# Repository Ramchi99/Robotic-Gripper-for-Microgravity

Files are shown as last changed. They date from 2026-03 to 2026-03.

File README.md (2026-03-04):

# Development of a Robotic Gripper for Microgravity Applications

<p align="center">
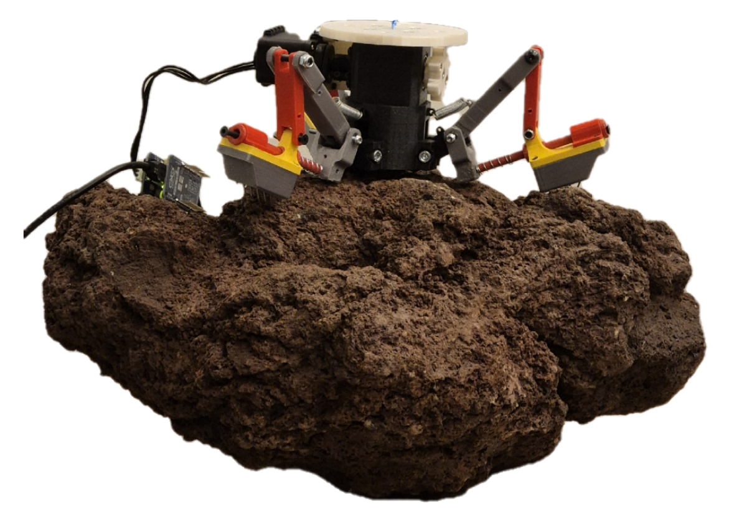
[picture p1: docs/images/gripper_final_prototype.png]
Physical Prototype of the Spacehopper Gripper
  
</p>

This repository contains the hardware designs, firmware, control software, and data evaluation for a functioning prototype of an underactuated robotic gripper designed for applications in microgravity. 

The gripper was developed as part of a Bachelor's Thesis, and is intended to be integrated into **Spacehopper**, an autonomous robot designed to jump in microgravity and reorient in the air to land safely. 

## Testing the Gripper

Here is a video of the final gripper mechanism in action:

<p align="center">
  Gripper in Action
</p>

*(If you prefer higher quality, **[click here to download or view the original .mp4 video](docs/images/gripper_stable.mp4)**)*

## Design Objectives

The mechanical design of this gripping mechanism aimed to fulfill the following primary objectives for reliable use on varied terrain in space:
1. **Reliable Static Gripping:** Ensure safe attachment to various relevant rocky surfaces.
2. **Microgravity Compatibility:** The mechanism must not rely on normal forces (gravity) to maintain its grip.
3. **Underactuated Design:** To reduce weight and complexity, the gripper is underactuated, using a single motor to drive all three legs via a differential mechanism, combined with a spring-loaded passive release mechanism.
4. **Space-Grade Design Principles:** While the current prototype is primarily 3D printed, the architecture is designed such that it can be manufactured using space-gradable materials in the future. This means avoiding components prone to dust jamming (like exposed gears) and avoiding compliant materials (like soft polymers) that would rapidly degrade in the space environment.

## Repository Structure

This repository is structured for modularity and easy reproduction. You'll find everything you need to build the physical gripper, program its microcontroller, and evaluate its physical performance using the custom ROS control interface.

```text
Robotic-Gripper-for-Microgravity/
├── hardware/                 # Everything needed to physically build the gripper
│   ├── Gripper_V06.stl       # Full 3D Assembly Model (Interactive in browser)
│   ├── cad/                  # Source CAD files (e.g., .prt, .stp, .3mf) 
│   │   └── design_iterations/# Historical CAD files for previous gripper versions (V01-V05)
│   └── stl/                  # Ready-to-print 3D models for the individual parts
│
├── firmware/                 # Code that runs directly on the microcontrollers
│   └── ax12a_controller/     # Arduino code (.ino) for Dynamixel AX-12A motors
│
├── software/                 # High-level software, ROS nodes, and testing scripts
│   └── franka_ft_reader/     # ROS package containing the controller nodes and measurement logger
│
├── data_evaluation/          # Data collected during physical testing on different rock types
│   ├── notebooks/            # Jupyter notebooks containing the evaluation scripts and plots
│   └── raw_data/             # Raw .csv logs from the Franka arm tests
│
└── docs/                     # Documentation and final reports
    ├── Climbing_robotic_gripper_report.pdf # Final detailed Bachelor Thesis report
    └── Final_Presentation_Slides.pdf       # Summary presentation of the project
```

## Hardware & Manufacturing

**[Click here to view the Interactive 3D Assembly Model of the Gripper](hardware/Gripper_V06.stl)**

> **Important Note regarding CAD vs. Physical Prototype:**
> The `Gripper_V06.prt` file represents the final *modeled* iteration of the design. However, during physical testing, spontaneous and rapid modifications had to be made to the gripper legs to achieve a functional grip. These final manual adjustments are **not** reflected in the CAD files, but can be seen in the photographs within the final thesis report. 

The physical prototype is composed of custom 3D printed parts and off-the-shelf Dynamixel Actuators. 
* To print your own parts, head over to `hardware/stl`. 
* To modify the design, refer to the CAD source files inside `hardware/cad`. 
* Detailed assembly instructions, kinematic diagrams, and mechanical analysis can be found inside the final report located in `docs/`.

## Software & Testing

The `software` directory contains the `franka_ft_reader` ROS package. This package was used to drive a Franka Emika Panda robotic arm to perform repeatable, precise force interactions with the gripper against various asteroid-analog rock samples (Asphalt, Limestone, Volcanic Lava Rock, Breccia, Slate, and Sediment). 

### Dependencies
* ROS Noetic (or compatible)
* [franka_ros](https://frankaemika.github.io/docs/franka_ros.html)

## Data & Evaluation

Detailed evaluations of the grip strength, spine angles (40 to 90 degrees), and dynamic shock responses are provided in the `data_evaluation` directory. 
* **Raw test data:** Available as `.csv` logs under `data_evaluation/raw_data`.
* **Plots and analysis:** Jupyter Notebooks demonstrating exactly how the data was cleaned and analyzed are located in `data_evaluation/notebooks`.

---
## License and Copyright

This project is licensed under the MIT License. This means you are free to use, copy, modify, merge, publish, distribute, sublicense, and/or sell copies of the software and hardware designs, provided that the original copyright notice and permission notice are included in all copies or substantial portions of the work.

*Copyright (c) 2024 Fiona Martin and Simon Ramchandani. Created as part of a Bachelor's Thesis project affiliated with the ETH Robotic Systems Lab.*

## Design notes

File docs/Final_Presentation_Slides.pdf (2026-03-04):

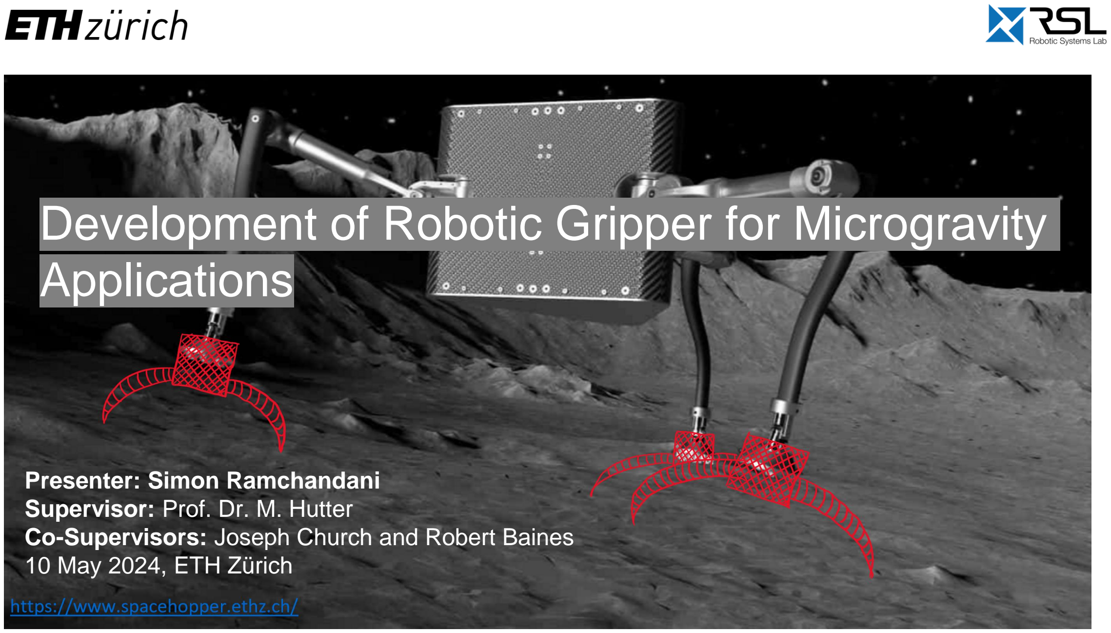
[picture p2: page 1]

# Development of Robotic Gripper for Microgravity Applications

Presenter: Simon Ramchandani
Supervisor: Prof. Dr. M. Hutter
Co-Supervisors: Joseph Church and Robert Baines 10 May 2024, ETH Zürich

## Motivation for the whole projects

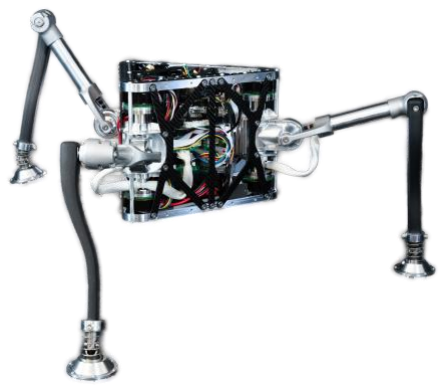
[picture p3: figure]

- Exploring surface of asteroids and other microgravitational environments
- Design a robotic gripper for robots like Spacehopper

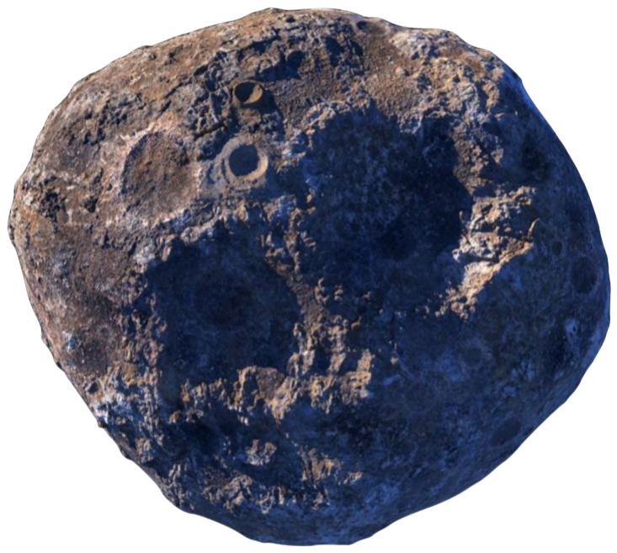
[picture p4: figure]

- Considerations:
- grasp and hold on to rocks
- should work in zero gravity
- designed for space
06.05.2020 | 2

## Overview and division of workload

Fiona
- Design of gripping mechanism

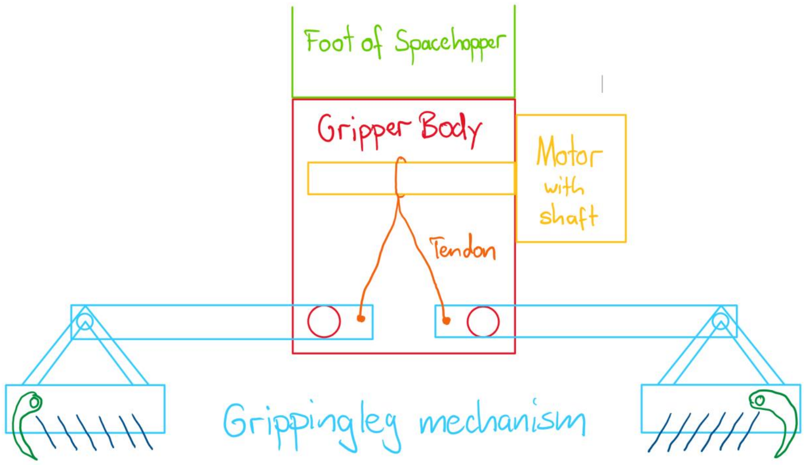
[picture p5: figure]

Simon
- Design of gripper body
- Actuation of gripper
- Setup and conducting tests:

-selecting rock to gripp

- determining the capable adhesion force in tangential and normal direction
- test different hooking mechanisms

## Gripper body Design

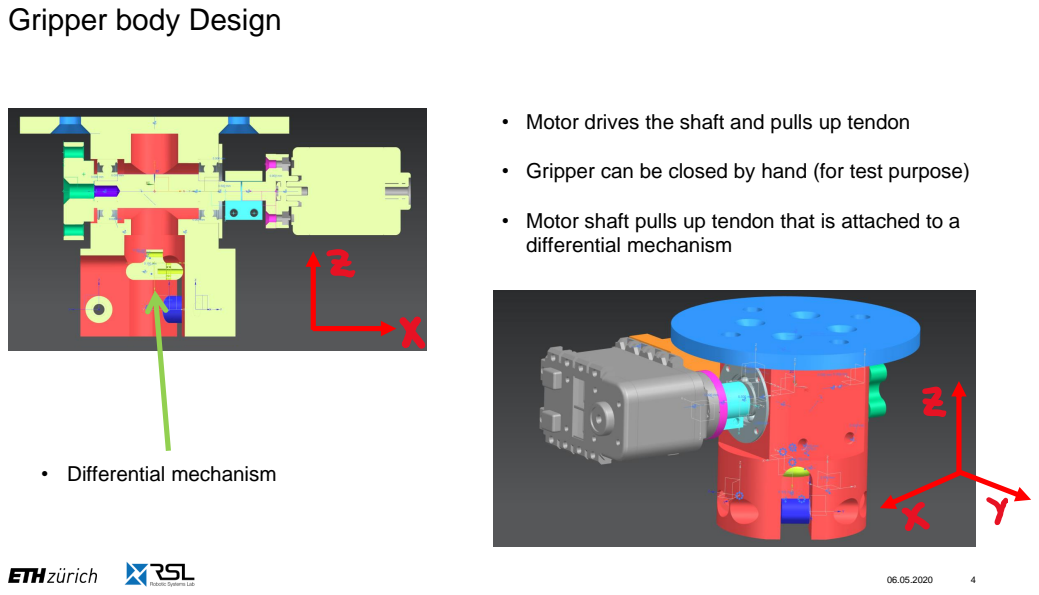
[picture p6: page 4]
• Differential mechanism

• Motor drives the shaft and pulls up tendon

• Gripper can be closed by hand (for test purpose)

• Motor shaft pulls up tendon that is attached to a
differential mechanism

## Gripper body Design – Differential mechanism

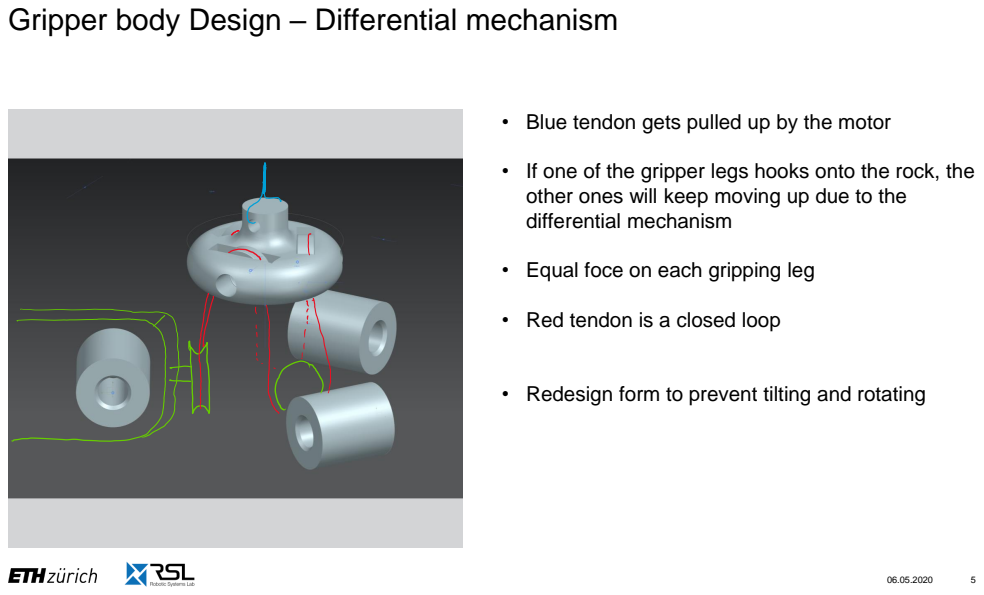
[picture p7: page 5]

• Blue tendon gets pulled up by the motor

• If one of the gripper legs hooks onto the rock, the
other ones will keep moving up due to the
differential mechanism

• Equal foce on each gripping leg

• Red tendon is a closed loop

• Redesign form to prevent tilting and rotating

## Testing – Two main hooking mechanism

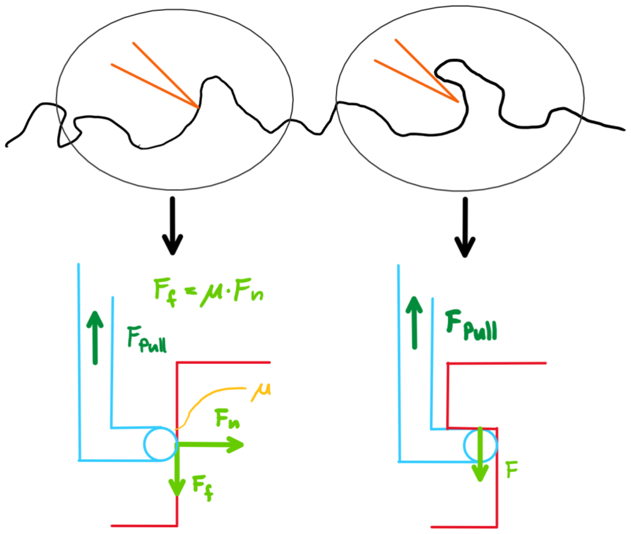
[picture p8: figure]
First Mechanism - Friction

- 1. Mechanism based on friction (left)

The bigger the generated force in tangential direction, the bigger the the capable pulling force

- 2. Mechanism based on geometry (right)

For this the geometry and angle of the spine is the main contributing factor

(a force in tangential direction is necessary to keep the spine in his place)

## Test setup in the literature

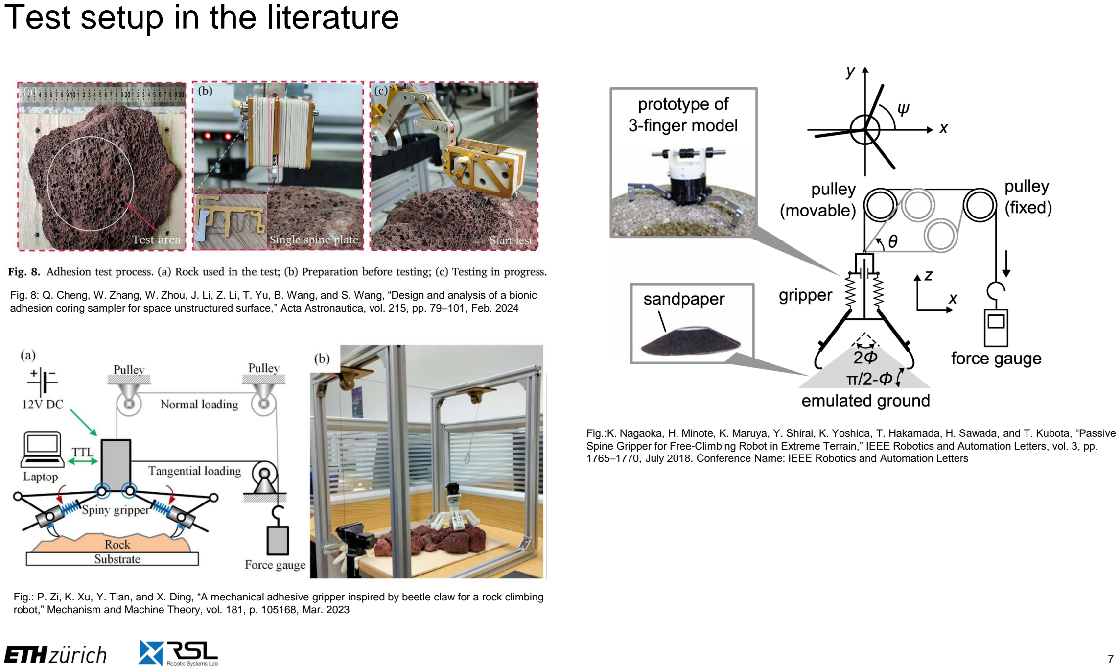
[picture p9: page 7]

7

Fig. 8: Q. Cheng, W. Zhang, W. Zhou, J. Li, Z. Li, T. Yu, B. Wang, and S. Wang, “Design and analysis of a bionic adhesion coring sampler for space unstructured surface,” Acta Astronautica, vol. 215, pp. 79–101, Feb. 2024

Fig.: P. Zi, K. Xu, Y. Tian, and X. Ding, “A mechanical adhesive gripper inspired by beetle claw for a rock climbing robot,” Mechanism and Machine Theory, vol. 181, p. 105168, Mar. 2023

Fig.:K. Nagaoka, H. Minote, K. Maruya, Y. Shirai, K. Yoshida, T. Hakamada, H. Sawada, and T. Kubota, “Passive Spine Gripper for Free-Climbing Robot in Extreme Terrain,” IEEE Robotics and Automation Letters, vol. 3, pp. 1765–1770, July 2018. Conference Name: IEEE Robotics and Automation Letters

## Test setup

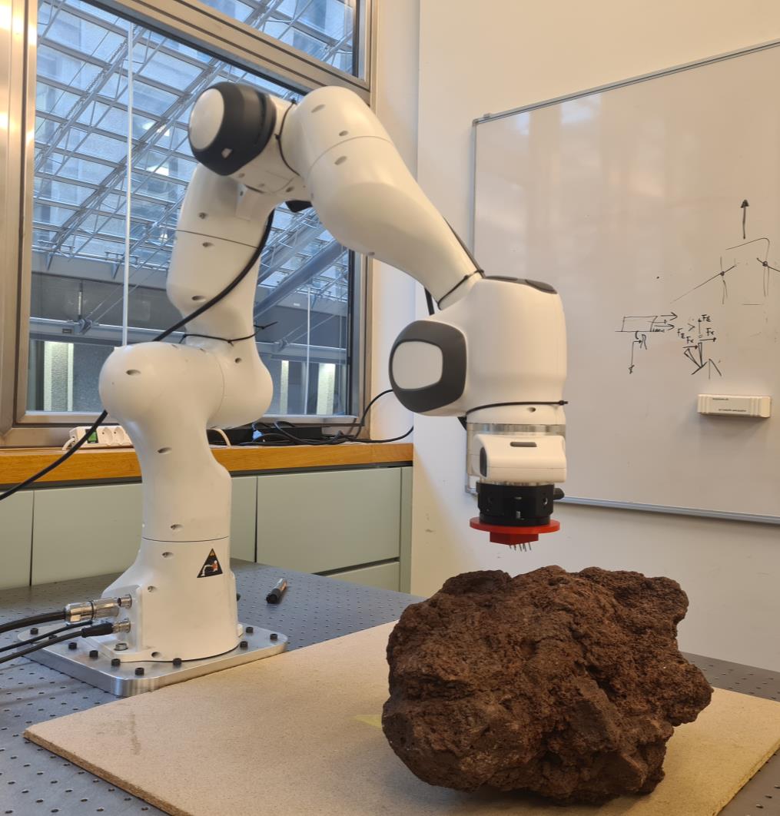
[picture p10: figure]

- Gripper or subpart of gripper attached to Franka arm with force-torque-sensor

versatile in the movement of the arm

measure forces and torques in all directions

- Decided to test on porous volcanic rock

exists widely on mars and other numerous planets

unregular surface to capture as many surface structures as possible

8

## Testing tangential force (y-force)

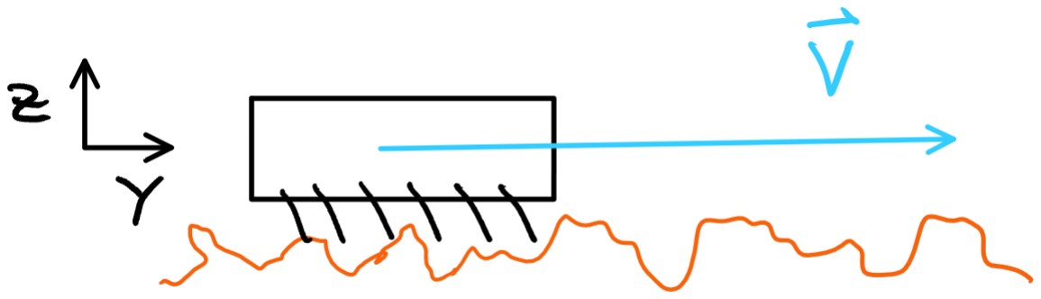
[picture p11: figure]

- Track velocity in y-direction with Franka-Arm
- Measure the forces in x, y and z direction
- Primarily interested in the capable y-force bevor detaching

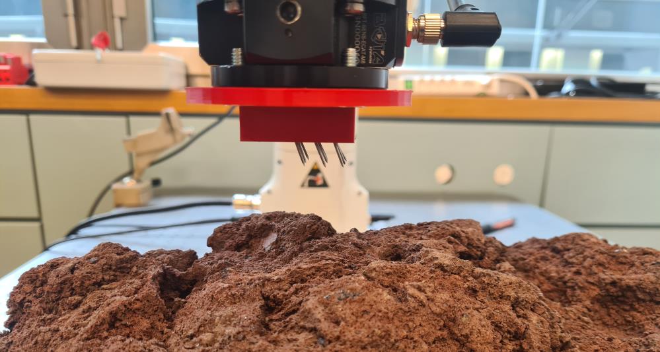
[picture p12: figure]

- Test different spine angles

## Testing tangential force (y-force)

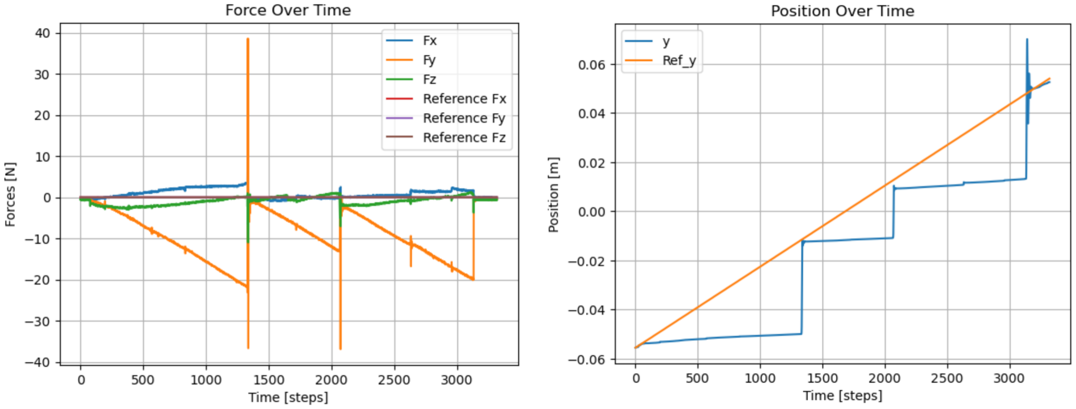
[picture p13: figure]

- Approximately 10 to 20 Newtons before detaching

10

## Future Testing – pulling force and hook implementation

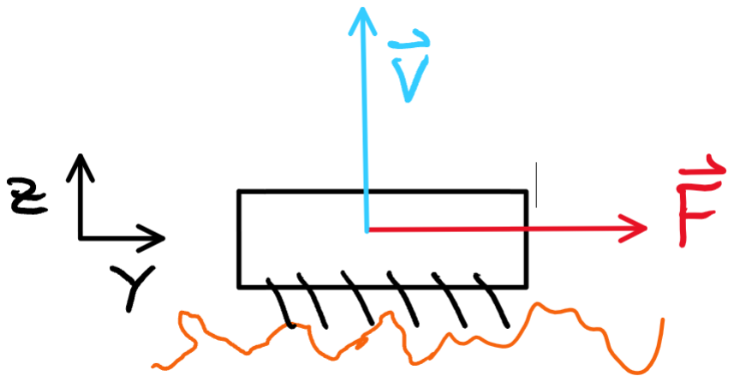
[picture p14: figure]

- Apply force in y direction and velocity in z direction
- Measure the z force (pulling force)

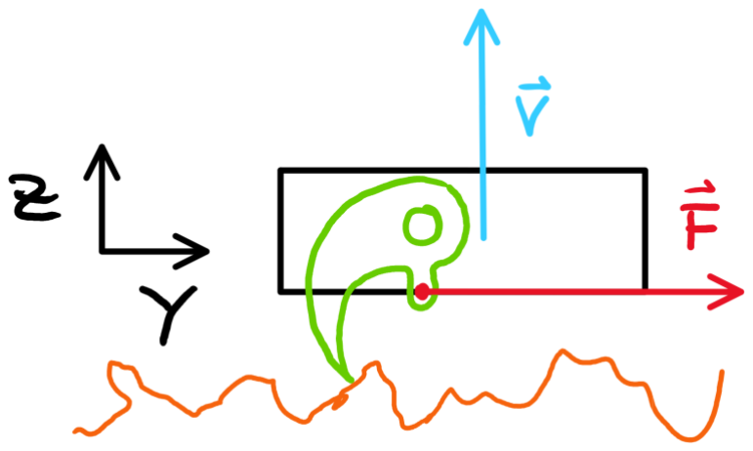
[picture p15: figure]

- Test hook mechanism with different configurations
- Also measure the z force

12

Simon Ramchandani
Student
simonra@student.ethz.ch

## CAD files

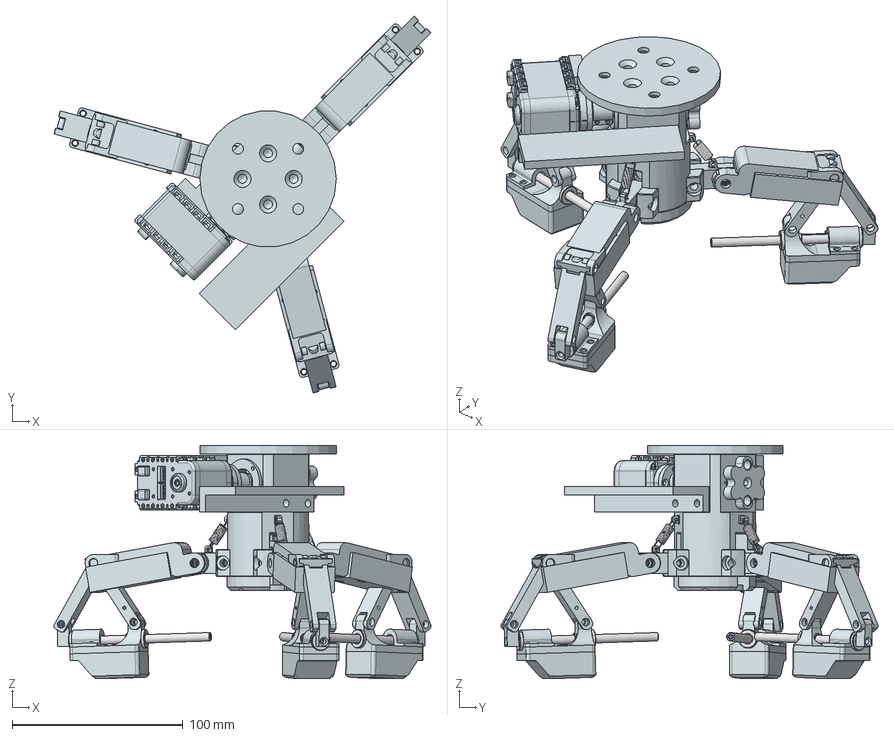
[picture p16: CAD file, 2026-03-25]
hardware/step/Gripper_V06.stp
221.0 x 221.0 x 136.8 mm
motor_adapter_06_3D
Adapter_V02
tendon_differential
pulley_differential x 12
ballbearing_fix
motor_axel_02
tendon_differential_02
PRT0001
PRT0002
PRT0003 x 4
PRT0004 x 2
PRT0005
PRT0006
PRT0007
skf_bearing_626_2_x_t x 2
dynamixel_adapter
dynamixel_axle_02
fixing_device_3D
kupplung_02
Rock_01
dowel_pin x 3
skf_bearing_w_618_1_5_2_x_t x 3
tendon_differential_04
arduino_holder
testleg_05 x 3
gripperleg x 3
Block_90_degree x 3
Sodemann 40900_step x 3
floor_for_body
nds_000001_001_M_link_body1 x 3
001_000001_001_M_Link1_f1 x 3
001_000001_001_M_Link2_f1 - Copy x 3
001_000001_001_M_insert x 3
nds_000001_001_M_top_x1block x 3
nds_000001_001_M_Holder_links x 3
bushing inner d_5_ L_12 x 6
nds_000002_031_M_Block_50 x 3
SSFJW5-85-M3-N3 x 3

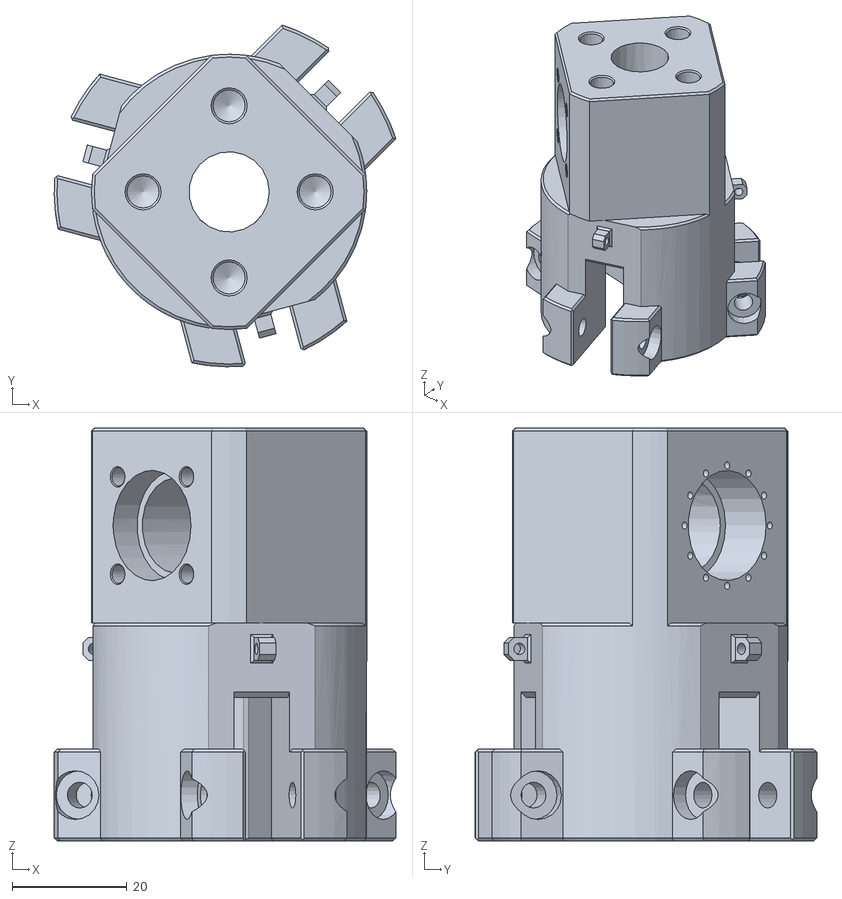
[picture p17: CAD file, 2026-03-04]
hardware/stl/motor_adapter_06_3D.stl
59.6 x 59.6 x 72.0

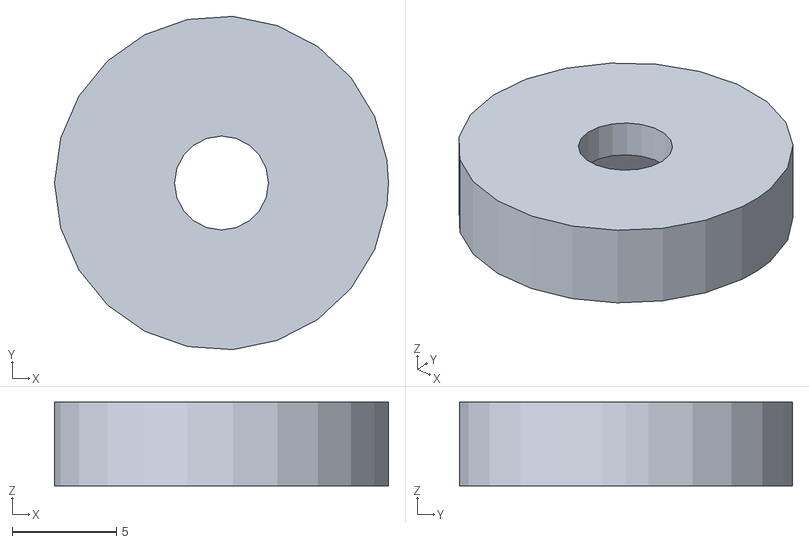
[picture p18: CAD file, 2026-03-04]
hardware/stl/fixing_disk.stl
16.0 x 16.0 x 4.00

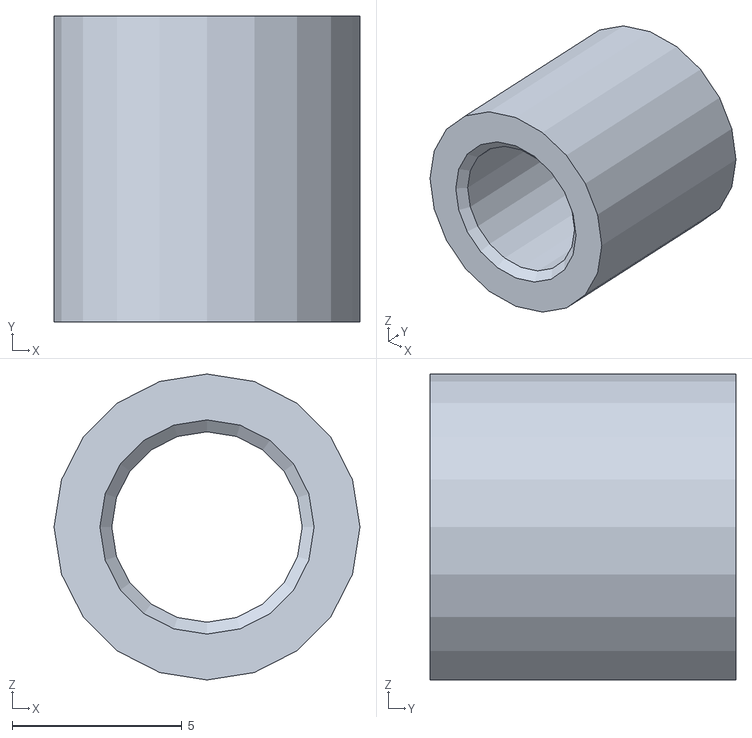
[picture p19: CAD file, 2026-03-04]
hardware/stl/dowel_pin_3D.stl
9.00 x 9.00 x 9.00

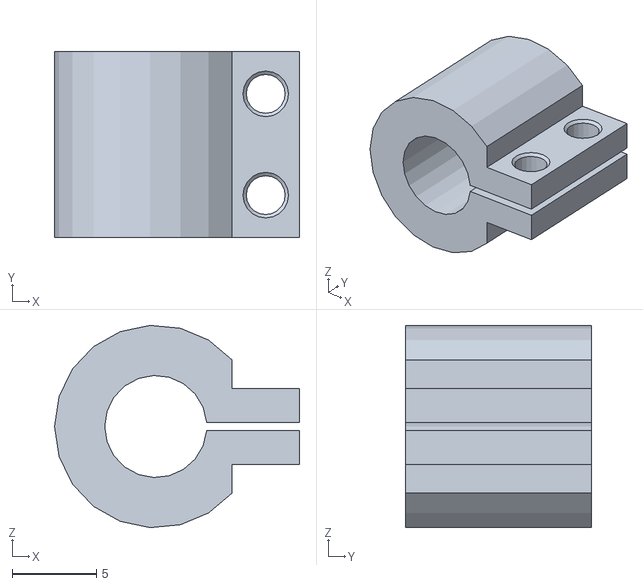
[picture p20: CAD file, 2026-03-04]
hardware/stl/kupplung_3D.stl
14.5 x 11.0 x 12.0

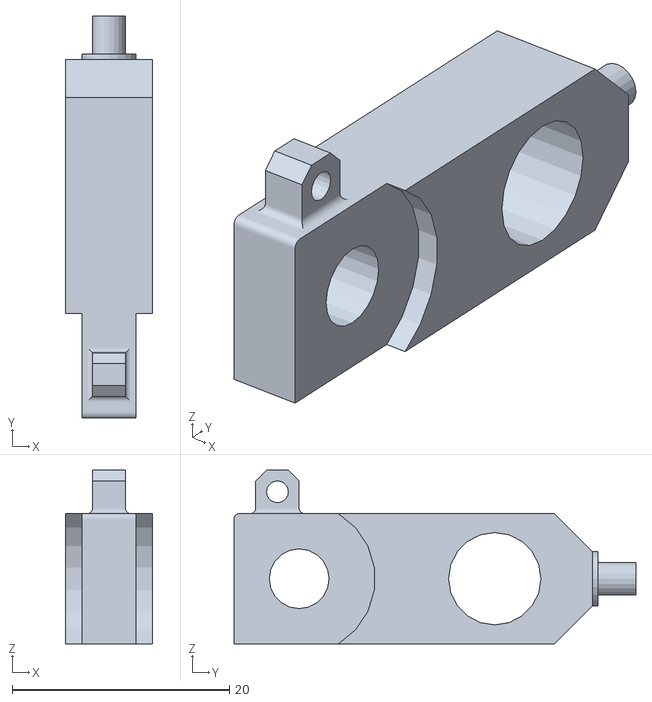
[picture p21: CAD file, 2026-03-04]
hardware/stl/testleg_04.stl
8.00 x 37.0 x 16.0

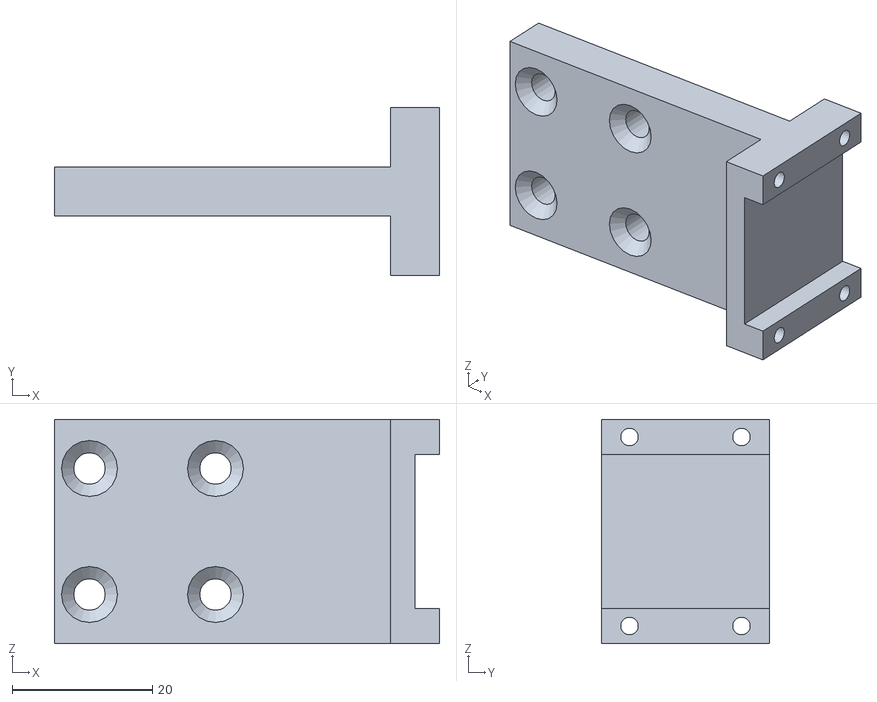
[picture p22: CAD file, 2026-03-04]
hardware/stl/dynamixel_adapter.stl
55.0 x 24.0 x 32.0

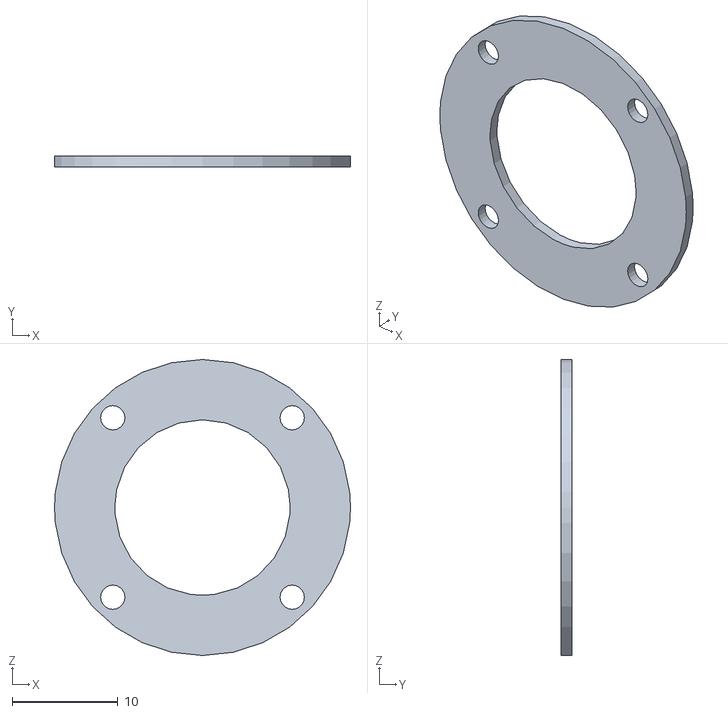
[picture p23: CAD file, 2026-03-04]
hardware/stl/ballbearing_fix.stl
28.0 x 1.00 x 28.0

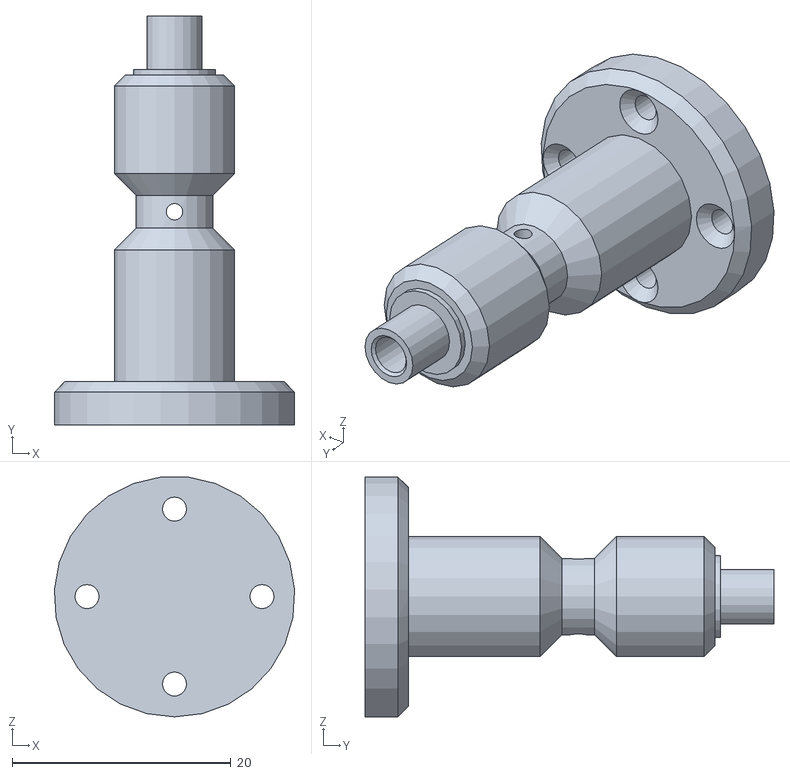
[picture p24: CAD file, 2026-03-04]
hardware/stl/motor_shaft_3D_printing.stl
22.0 x 37.4 x 21.9

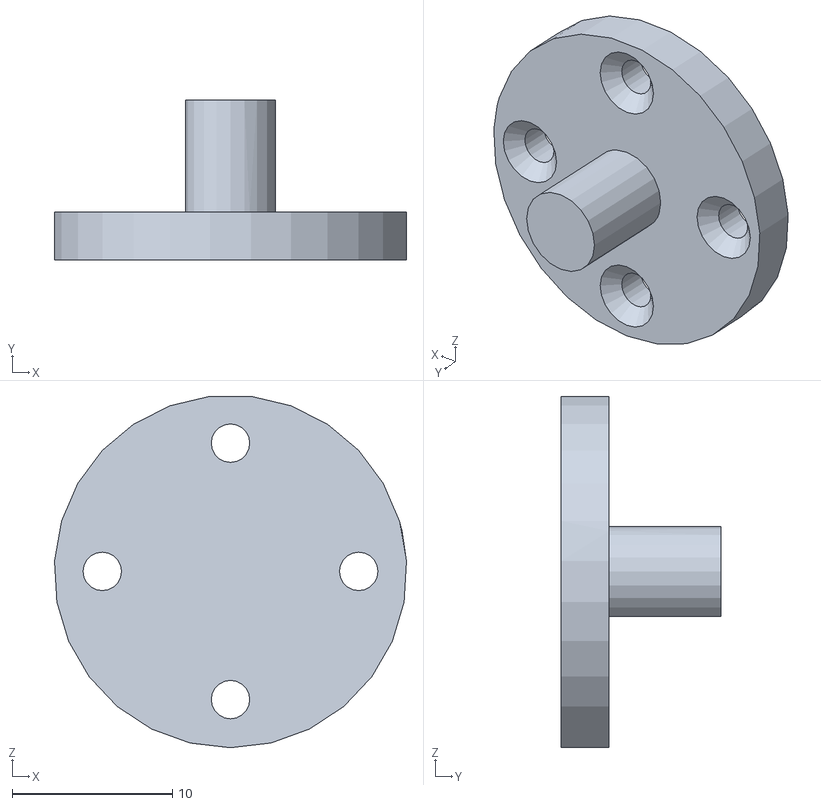
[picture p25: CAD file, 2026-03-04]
hardware/stl/dynamixel_axle.stl
22.0 x 10.0 x 21.9

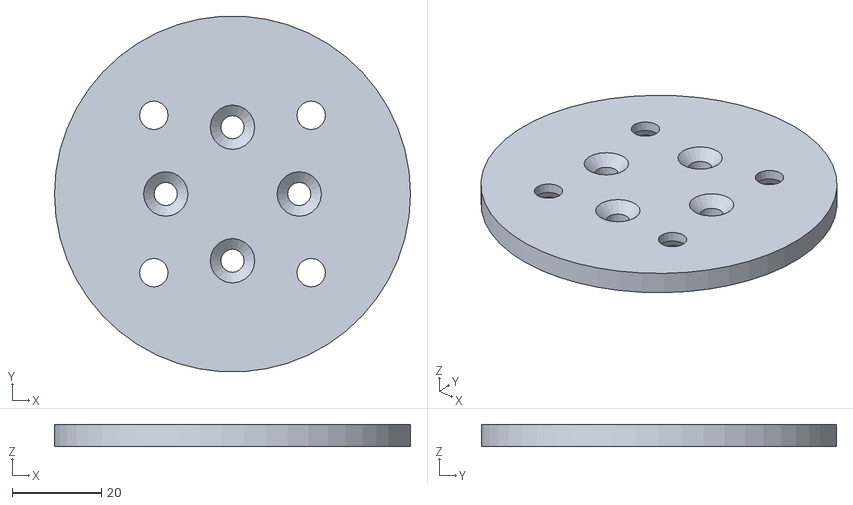
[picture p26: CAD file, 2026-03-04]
hardware/stl/Adapter_V02_3D.stl
80.0 x 79.8 x 5.00

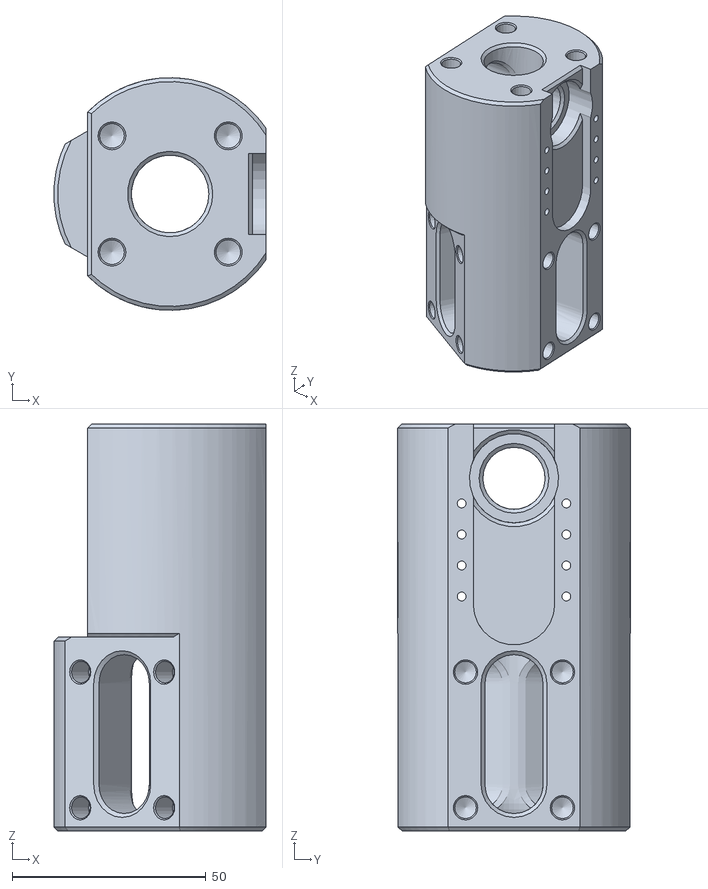
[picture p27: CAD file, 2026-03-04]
hardware/stl/motor_adapter_03_3D_printing.stl
54.7 x 60.0 x 105.0

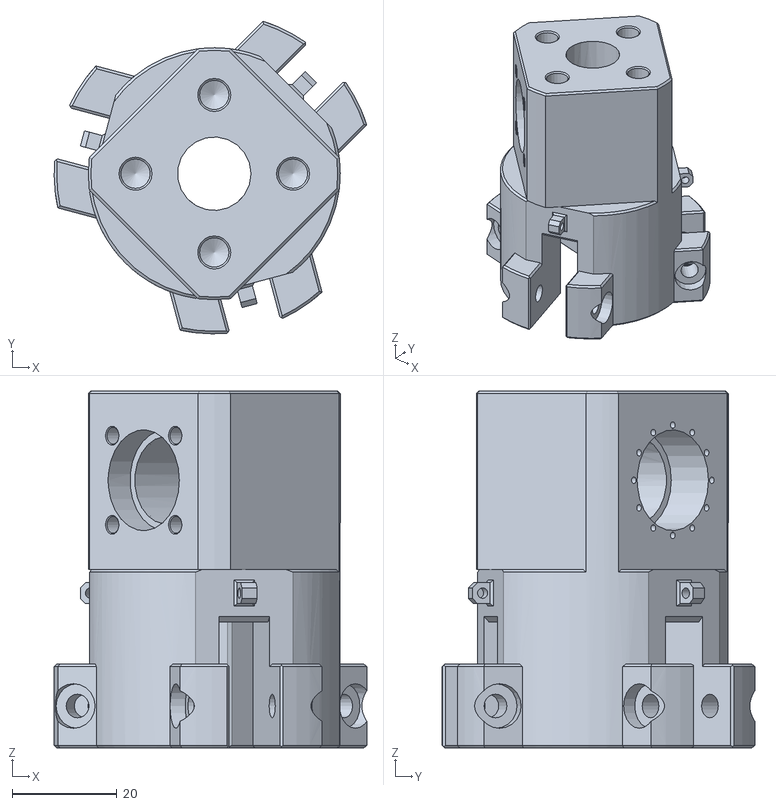
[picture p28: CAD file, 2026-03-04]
hardware/stl/motor_adapter_05_3D_longer.stl
59.6 x 59.6 x 68.0

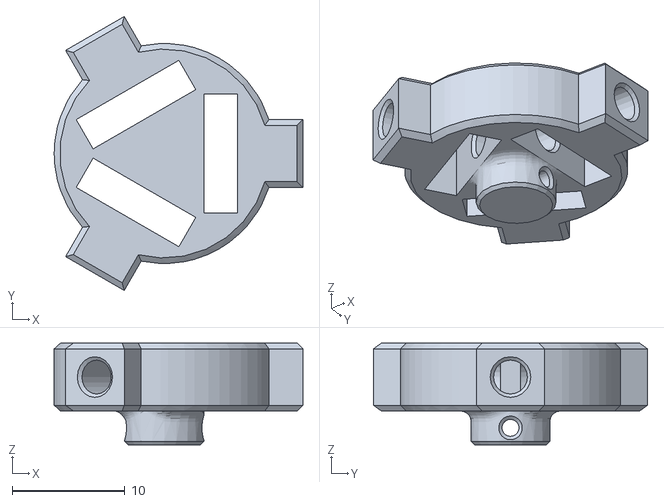
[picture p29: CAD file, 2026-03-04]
hardware/stl/tendon_differential_04.stl
22.0 x 24.3 x 9.00

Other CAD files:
hardware/stl/motor_adapter_05_3D.stl
hardware/stl/linkage_pin_3D_printing.stl
hardware/stl/tendon_differential_04_2.stl
hardware/stl/tendon_linkage_part_03_3D_printing.stl
hardware/cad/001_000001_001_M_Link1_f1.prt
hardware/cad/001_000001_001_M_Link2_f1 - Copy.prt
hardware/cad/001_000001_001_M_insert.prt
hardware/cad/ASM0002_ASM.prt
hardware/cad/AX-12A_stp.prt
hardware/cad/Adapter_V02.prt
hardware/cad/Block_90_degree.prt
hardware/cad/Gripper_V06.prt
hardware/cad/PRT0001.prt
hardware/cad/PRT0002.prt
hardware/cad/PRT0003.prt
hardware/cad/PRT0004.prt
hardware/cad/PRT0005.prt
hardware/cad/PRT0006.prt
hardware/cad/PRT0007.prt
hardware/cad/SSFJW5-85-M3-N3.prt
hardware/cad/Sodemann 40900_step.prt
hardware/cad/arduino_holder.prt
hardware/cad/ballbearing_fix.prt
hardware/cad/bushing inner d_5_ L_12.prt
hardware/cad/design_iterations/001_000001_00_M_Link1_body.prt
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

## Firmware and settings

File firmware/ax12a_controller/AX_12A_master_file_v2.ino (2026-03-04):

#include <DynamixelShield.h>

/*
Baud Rate Values for Dynamixel Motors:

Value   Baud Rate (bps)    Margin of Error
1       1M                  0.000%
3       500,000             0.000%
4       400,000             0.000%
7       250,000             0.000%
9       200,000             0.000%
16      115200              -2.124%
34      57600               0.794%
103     19200               -0.160%
207     9600                -0.160%
*/

#if defined(ARDUINO_AVR_UNO) || defined(ARDUINO_AVR_MEGA2560)
  #include <SoftwareSerial.h>
  SoftwareSerial soft_serial(7, 8); // DYNAMIXELShield UART RX/TX
  #define DEBUG_SERIAL soft_serial
#elif defined(ARDUINO_SAM_DUE) || defined(ARDUINO_SAM_ZERO)
  #define DEBUG_SERIAL SerialUSB    
#else
  #define DEBUG_SERIAL Serial
#endif

//This example is written for DYNAMIXEL AX-12A with Protocol 1.0.

#define OPERATING_MODE_ADDR_LEN     2

/*The Control Table is divided into 2 Areas. 
Data in the RAM Area is reset to initial values 
when the power is reset(Volatile). On the other 
hand, data in the EEPROM Area is maintained even 
when the device is powered off(Non-Volatile).*/

//Control Table of EEPROM Area
#define MODEL_NUMBER_ADDR           0
#define MODEL_NUMBER_ADDR_LEN       2
#define FIRMWARE_VERSION_ADDR       2
#define FIRMWARE_VERSION_ADDR_LEN   1
#define ID_ADDR                     3
#define ID_ADDR_LEN                 1
#define BAUDRATE_ADDR               4
#define BAUDRATE_ADDR_LEN           1
#define RETURN_DELAY_TIME_ADDR      5
#define RETURN_DELAY_TIME_ADDR_LEN  1
#define CW_ANGLE_LIMIT_ADDR         6
#define CW_ANGLE_LIMIT_ADDR_LEN     2
#define CCW_ANGLE_LIMIT_ADDR        8
#define CCW_ANGLE_LIMIT_ADDR_LEN    2
#define TEMPERATURE_LIMIT_ADDR      11
#define TEMPERATURE_LIMIT_ADDR_LEN  1
#define MIN_VOLTAGE_LIMIT_ADDR      12
#define MIN_VOLTAGE_LIMIT_ADDR_LEN  1
#define MAX_VOLTAGE_LIMIT_ADDR      13
#define MAX_VOLTAGE_LIMIT_ADDR_LEN  1
#define MAX_TORQUE_ADDR             14
#define MAX_TORQUE_ADDR_LEN         2
#define STATUS_RETURN_LEVEL_ADDR    16
#define STATUS_RETURN_LEVEL_ADDR_LEN 1
#define ALARM_LED_ADDR              17
#define ALARM_LED_ADDR_LEN          1
#define SHUTDOWN_ADDR               18
#define SHUTDOWN_ADDR_LEN           1

//Control Table of RAM Area
#define TORQUE_ENABLE_ADDR           24
#define TORQUE_ENABLE_ADDR_LEN       1
#define LED_ADDR                     25
#define LED_ADDR_LEN                 1
#define CW_COMPLIANCE_MARGIN_ADDR    26
#define CW_COMPLIANCE_MARGIN_ADDR_LEN 1
#define CCW_COMPLIANCE_MARGIN_ADDR   27
#define CCW_COMPLIANCE_MARGIN_ADDR_LEN 1
#define CW_COMPLIANCE_SLOPE_ADDR     28
#define CW_COMPLIANCE_SLOPE_ADDR_LEN 1
#define CCW_COMPLIANCE_SLOPE_ADDR    29
#define CCW_COMPLIANCE_SLOPE_ADDR_LEN 1
#define GOAL_POSITION_ADDR           30
#define GOAL_POSITION_ADDR_LEN       2
#define MOVING_SPEED_ADDR            32
#define MOVING_SPEED_ADDR_LEN        2
#define TORQUE_LIMIT_ADDR            34
#define TORQUE_LIMIT_ADDR_LEN        2
#define PRESENT_POSITION_ADDR        36
#define PRESENT_POSITION_ADDR_LEN    2
#define PRESENT_SPEED_ADDR           38
#define PRESENT_SPEED_ADDR_LEN       2
#define PRESENT_LOAD_ADDR            40
#define PRESENT_LOAD_ADDR_LEN        2
#define PRESENT_VOLTAGE_ADDR         42
#define PRESENT_VOLTAGE_ADDR_LEN     1
#define PRESENT_TEMPERATURE_ADDR     43
#define PRESENT_TEMPERATURE_ADDR_LEN 1
#define REGISTERED_ADDR              44
#define REGISTERED_ADDR_LEN          1
#define MOVING_ADDR                  46
#define MOVING_ADDR_LEN              1
#define LOCK_ADDR                    47
#define LOCK_ADDR_LEN                1
#define PUNCH_ADDR                   48
#define PUNCH_ADDR_LEN               2

#define TIMEOUT 100    //default communication timeout 10ms



const uint8_t DXL_ID = 1;
const float DXL_PROTOCOL_VERSION = 1.0;
const uint32_t baudrate = 1000000;

DynamixelShield dxl;

//use as parameters for some configurations

uint8_t returned_id = 0;
uint8_t returned_baudrate = 0;
uint16_t present_position = 0;
uint16_t present_speed = 0;

uint8_t turn_on = 1;
uint8_t turn_off = 0;

uint16_t goalPosition1 = 300;
uint16_t goalPosition2 = 500;

float Kp = 2; // Proportional gain
uint16_t goal_position = 1022; // Default goal position (middle of the range)


void setup() {
  DEBUG_SERIAL.begin(115200);   // Set debugging port baudrate to 115200bps
  while(!DEBUG_SERIAL);         // Wait until the serial port for terminal is opened

  // Set Port baudrate to 1000000bps. This has to match with DYNAMIXEL baudrate (AX-12A).
  dxl.begin(baudrate);
  
  // Set Port Protocol Version. This has to match with DYNAMIXEL protocol version.
  dxl.setPortProtocolVersion(DXL_PROTOCOL_VERSION);

  DEBUG_SERIAL.print("Read for PROTOCOL ");
  DEBUG_SERIAL.print(DXL_PROTOCOL_VERSION, 1);
  DEBUG_SERIAL.print(", ID ");
  DEBUG_SERIAL.println(DXL_ID);

  // Read DYNAMIXEL ID
  dxl.read(DXL_ID, ID_ADDR, ID_ADDR_LEN, (uint8_t*)&returned_id, sizeof(returned_id), TIMEOUT);
  DEBUG_SERIAL.print("ID : ");
  DEBUG_SERIAL.println(returned_id);
  delay(100);
  
  // Read DYNAMIXEL Baudrate
  dxl.read(DXL_ID, BAUDRATE_ADDR, BAUDRATE_ADDR_LEN, (uint8_t*)&returned_baudrate, sizeof(returned_baudrate), TIMEOUT);
  DEBUG_SERIAL.print("Baud Rate : ");
  DEBUG_SERIAL.println(returned_baudrate);
  delay(100);
  
  // Read DYNAMIXEL Present Position
  dxl.read(DXL_ID, PRESENT_POSITION_ADDR, PRESENT_POSITION_ADDR_LEN, (uint8_t*)&present_position, sizeof(present_position), TIMEOUT);
  DEBUG_SERIAL.print("Present Position : ");
  DEBUG_SERIAL.println(present_position);

  // It configures the Dynamixel motor to joint mode, limiting its rotation within specified angles.
  delay(10);
  
  // Turn off torque when configuring items in EEPROM area
  if(dxl.write(DXL_ID, TORQUE_ENABLE_ADDR, (uint8_t*)&turn_off , TORQUE_ENABLE_ADDR_LEN, TIMEOUT))
    DEBUG_SERIAL.println("DYNAMIXEL Torque off");
  else
    DEBUG_SERIAL.println("Error: Torque off failed");

  delay(10);
  
  // Set CW and CCW angle limits for joint mode (min position = 300, max position = 700)
  uint16_t min_position = 0;
  uint16_t max_position = 1023; //0; //
  if(dxl.write(DXL_ID, CW_ANGLE_LIMIT_ADDR, (uint8_t*)&min_position, CW_ANGLE_LIMIT_ADDR_LEN, TIMEOUT)
        && dxl.write(DXL_ID, CCW_ANGLE_LIMIT_ADDR, (uint8_t*)&max_position, CCW_ANGLE_LIMIT_ADDR_LEN, TIMEOUT))
    DEBUG_SERIAL.println("Set operating mode");
  else
    DEBUG_SERIAL.println("Error: Set operating mode failed");

  delay(10);
  
  // Set goal position to 300
  uint16_t goal_position = 1023;
  if(dxl.write(DXL_ID, GOAL_POSITION_ADDR, (uint8_t*)&goal_position, GOAL_POSITION_ADDR_LEN, TIMEOUT))
    DEBUG_SERIAL.println("Set goal position");
  else
    DEBUG_SERIAL.println("Error: Set goal position failed / Or motor is in wheel mode!");

  delay(10);

  

  // Set maximum torque 
  uint16_t max_torque = 1023 * 0.15; // 15% of max torque (1023)
  if(dxl.write(DXL_ID, MAX_TORQUE_ADDR, (uint8_t*)&max_torque, MAX_TORQUE_ADDR_LEN, TIMEOUT))
    DEBUG_SERIAL.println("Set max torque");
  else
    DEBUG_SERIAL.println("Error: Set max torque failed");

  delay(10);

  // Set torque limit 
  uint16_t torque_limit = 1023 * 0.15; // 15% of max torque (1023)
  if(dxl.write(DXL_ID, TORQUE_LIMIT_ADDR, (uint8_t*)&torque_limit, TORQUE_LIMIT_ADDR_LEN, TIMEOUT))
    DEBUG_SERIAL.println("Set torque limit");
  else
    DEBUG_SERIAL.println("Error: Set torque limit failed");

  delay(10);

  // Turn on torque
  if(dxl.write(DXL_ID, TORQUE_ENABLE_ADDR, (uint8_t*)&turn_on, TORQUE_ENABLE_ADDR_LEN, TIMEOUT))
    DEBUG_SERIAL.println("Torque on");
  else
    DEBUG_SERIAL.println("Error: Torque on failed");
}


void loop() {

  delay(20);
  //readLoad();
  //controlMotor();
  //readSpeed();
  controlMotorInJointMode();
  //currentPosition();
  //controlLoop();
  //updateGoalPosition();

}

/*
void moveMotor(uint16_t start, uint16_t end) {
  uint16_t currentPos = start;
  while (currentPos != end) {
    //DEBUG_SERIAL.print("Moving to position: ");
    //DEBUG_SERIAL.println(end);
    
    dxl.write(DXL_ID, GOAL_POSITION_ADDR, (uint8_t*)&end, GOAL_POSITION_ADDR_LEN, TIMEOUT);
    
    // Continuously read present position until goal is reached
    do {
      dxl.read(DXL_ID, PRESENT_POSITION_ADDR, PRESENT_POSITION_ADDR_LEN, (uint8_t*)&currentPos, sizeof(currentPos), TIMEOUT);
      //DEBUG_SERIAL.print("Current Position: ");
      DEBUG_SERIAL.println(currentPos);
      delay(100); // Adjust delay according to your motor's speed
    } while (currentPos != end);
  }
}
*/


void readLoad() {
  uint16_t loadValue = 0;
  dxl.read(DXL_ID, PRESENT_LOAD_ADDR, PRESENT_LOAD_ADDR_LEN, (uint8_t*)&loadValue, sizeof(loadValue), TIMEOUT);
  //DEBUG_SERIAL.print("Present Load: ");
  //DEBUG_SERIAL.println(loadValue);
  float load = convertLoadToPercentage(loadValue);
  DEBUG_SERIAL.println(loadValue);
  //DEBUG_SERIAL.println(load);
}

float convertLoadToPercentage(int loadValue) {
  // Convert load value to percentage
  float percentage = 0.0;
  
  // Check direction
  if (loadValue < 1024) {
    // CCW direction
    percentage = (loadValue / 10.23); // Convert to percentage
  } else {
    // CW direction
    percentage = ((1024 - loadValue) / 10.23); // Convert to percentage
  }
  
  return percentage;
}


uint16_t calculateSpeed(uint8_t percentage, bool clockwise) {
  if (percentage > 100) percentage = 100;
  uint16_t speed = (percentage * 1023) / 100; // Scale 0-100 to 0-1023
  if (clockwise) {
    speed += 1024; // Offset for clockwise direction
  }
  return speed;
}


/*
void readSpeed() {
  dxl.read(DXL_ID, PRESENT_SPEED_ADDR, PRESENT_SPEED_ADDR_LEN, (uint8_t*)&present_speed, sizeof(present_speed), TIMEOUT);
  
  int speedValue = present_speed & 0x3FF; // Mask out the direction bit (10th bit)
  bool clockwise = (present_speed & 0x400) != 0; // Check the direction bit
  
  int speedPercentage = (speedValue * 1000) / 1023; // Convert to percentage

  if (clockwise) {
    DEBUG_SERIAL.print("Current Speed: ");
    DEBUG_SERIAL.print(speedPercentage);
    DEBUG_SERIAL.println(" (CW)");
  } else {
    speedPercentage = -speedPercentage; // Make it negative for CCW
    DEBUG_SERIAL.print("Current Speed: ");
    DEBUG_SERIAL.print(speedPercentage);
    DEBUG_SERIAL.println(" (CCW)");
  }
}
*/

/*
void controlMotor() {
  static bool upPressed = false;
  static bool downPressed = false;
  static uint8_t speedPercentage = 5; // Default speed percentage (100% of max speed)

  if (Serial.available() > 0) {
    char command = Serial.read();
    if (command == 'u') {
      upPressed = true;
      downPressed = false;
    } else if (command == 'd') {
      downPressed = true;
      upPressed = false;
    } else if (command == 's') { // Stop command
      upPressed = false;
      downPressed = false;
    } else if (command >= '0' && command <= '9') {
      speedPercentage = (command - '0'); // * 10; // Set speed percentage (0-90%)
    }
  }

  if (upPressed) {
    uint16_t speed = calculateSpeed(speedPercentage, true);
    dxl.write(DXL_ID, MOVING_SPEED_ADDR, (uint8_t*)&speed, MOVING_SPEED_ADDR_LEN, TIMEOUT);
  } else if (downPressed) {
    uint16_t speed = calculateSpeed(speedPercentage, false);
    dxl.write(DXL_ID, MOVING_SPEED_ADDR, (uint8_t*)&speed, MOVING_SPEED_ADDR_LEN, TIMEOUT);
  } else {
    uint16_t speed = 0; // Stop the motor
    dxl.write(DXL_ID, MOVING_SPEED_ADDR, (uint8_t*)&speed, MOVING_SPEED_ADDR_LEN, TIMEOUT);
  }
}
*/

void controlMotorInJointMode() {
  static uint16_t goal_position = 1022; // Default goal position (middle of the range)
  static uint8_t speedPercentage = 100; // Default speed percentage (100% of max speed)
  bool positionChanged = false;
  uint16_t current_position = readPosition();
  
  if (Serial.available() > 0) {
    char command = Serial.read();
    if (command == 'u' && goal_position < 1013) {
      goal_position += 10; // Increase goal position
      positionChanged = true;
    } else if (command == 'd' && goal_position > 10) {
      goal_position -= 10; // Decrease goal position
      positionChanged = true;
    } else if (command >= '0' && command <= '9') {
      speedPercentage = (command - '0') * 10; // Set speed percentage (0-90%)
    }
  }

  if (positionChanged) {
    dxl.write(DXL_ID, GOAL_POSITION_ADDR, (uint8_t*)&goal_position, GOAL_POSITION_ADDR_LEN, TIMEOUT);
    uint16_t speed = calculateSpeed(speedPercentage, true);
    dxl.write(DXL_ID, MOVING_SPEED_ADDR, (uint8_t*)&speed, MOVING_SPEED_ADDR_LEN, TIMEOUT);
    //DEBUG_SERIAL.print("Goal Position: ");
    //DEBUG_SERIAL.println(goal_position);
    //Serial.print("   Present Position: ");
    //Serial.println(current_position);
  }
}


/*
void controlLoop() {
  // Read current position
  uint16_t current_position = readPosition();

  // Calculate error
  int16_t error = goal_position - current_position;

  // Calculate speed using proportional control
  int16_t speed = Kp * error;

  // Set the speed to drive the motor
  //dxl.write(DXL_ID, MOVING_SPEED_ADDR, (uint8_t*)&speed, MOVING_SPEED_ADDR_LEN, TIMEOUT);
  // Set the speed and direction to drive the motor
  if (speed >= 0) {
    dxl.write(DXL_ID, MOVING_SPEED_ADDR, (uint8_t*)&speed, MOVING_SPEED_ADDR_LEN, TIMEOUT);
  } else {
    // Set direction bit for CW direction
    speed = -speed; // Make speed positive
    speed |= 0x400; // Set direction bit
    dxl.write(DXL_ID, MOVING_SPEED_ADDR, (uint8_t*)&speed, MOVING_SPEED_ADDR_LEN, TIMEOUT);
  }

  // Print goal position and present position
  Serial.print("Goal Position: ");
  Serial.print(goal_position);
  Serial.print("   Present Position: ");
  Serial.println(current_position);

  // Delay for stability
  delay(100);
}
*/

uint16_t readPosition() {
  uint16_t current_position = 0;
  dxl.read(DXL_ID, PRESENT_POSITION_ADDR, PRESENT_POSITION_ADDR_LEN, (uint8_t*)&current_position, sizeof(current_position), TIMEOUT);
  return current_position;
}

void currentPosition() {
  uint16_t current_position = 0;
  dxl.read(DXL_ID, PRESENT_POSITION_ADDR, PRESENT_POSITION_ADDR_LEN, (uint8_t*)&current_position, sizeof(current_position), TIMEOUT);
  //Serial.print("   Current Position: ");
  //Serial.println(current_position);
}

void updateGoalPosition() {
  if (Serial.available() > 0) {
    char command = Serial.read();
    if (command == 'u' && goal_position < 1013) {
      goal_position += 10; // Increase goal position
    } else if (command == 'd' && goal_position > 10) {
      goal_position -= 10; // Decrease goal position
    }
  }
}

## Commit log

2026-03-04 Initial commit of Bachelor Thesis Gripper files
    [001_000001_001_M_Link1_f1.prt, 001_000001_001_M_Link2_f1 - Copy.prt, 001_000001_001_M_insert.prt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]
2026-03-04 Add prototype image and test video to README
2026-03-04 Change prototype image to final presentation clipping
2026-03-04 Remove unused prototype image
2026-03-04 Remove unused CAD tif image
2026-03-25 Add STEP export of the main gripper assembly
    [Gripper_V06.stp]
